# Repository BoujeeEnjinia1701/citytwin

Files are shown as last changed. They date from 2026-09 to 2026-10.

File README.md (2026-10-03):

# CityTwin

     

**Area:** Smart Cities · **TRL:** 3 of 9 (proof of concept on paper) · **Value-engineering target:** $750 USD for the kiosk (hypothetical control target; estimated cost $778.00) · **Difficulty:** 3 of 5

A city dashboard built on TwinKit that brings the smart city nodes together on a map and in a public kiosk, with open data export and privacy rules built in.

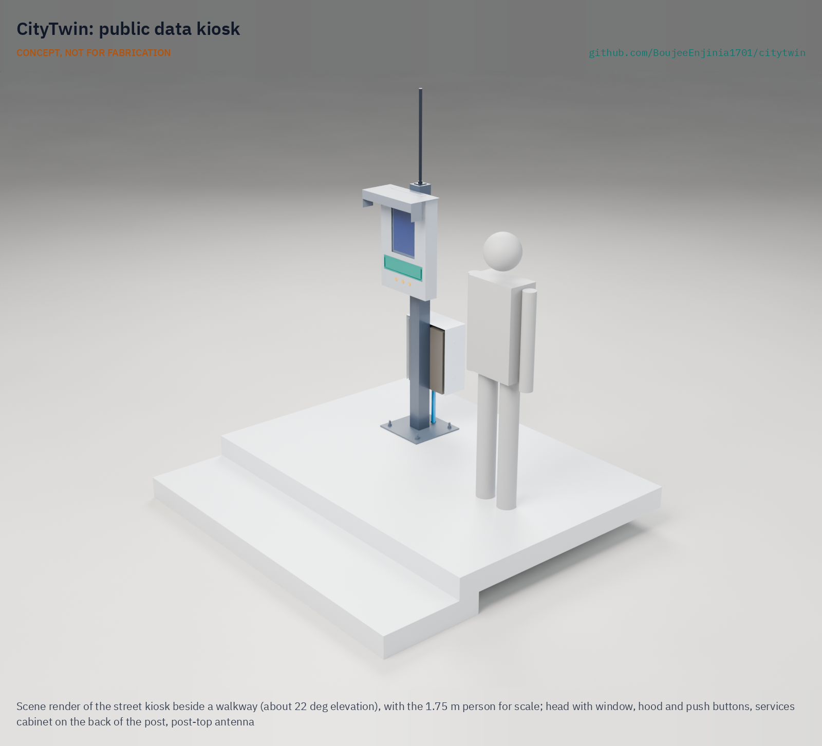
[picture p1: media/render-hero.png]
CityTwin: public kiosk for the city dashboard, photoreal render


[Interactive 3D model](media/viewer.html) · [Concept blueprint (PDF)](media/concept-blueprint.pdf) · [General arrangement CTW-DWG-001 (PDF)](cad/drawings/CTW-DWG-001.pdf) · [Calculations CTW-CAL-001](docs/04-calcs/01-sizing.md) · [Prototype build plan](docs/05-build-plan.md) · [Review note](docs/REVIEW.md)

## Concept rationale

One open, public view of street data builds trust and lets residents and planners use the same evidence. CityTwin takes the counts and levels that the lab's smart city nodes already send, checks each record against a strict schema, applies the same privacy rules to everything it publishes, and shows the result on one map, in hourly open data files and on a kiosk in the street. The kiosk tells a passer-by what is measured nearby, who is responsible and how long data is kept, next to the current values.

It is open and garage-buildable because trust depends on being able to check the system. The software runs on one small TwinKit gateway that a city, a university or a neighborhood group can own outright, and the kiosk is a steel post, a folded aluminum head, a color e-paper screen and an electrical cabinet: parts a local fabricator and electrician can supply and inspect.

## Burning platform

Cities are growing and are adding sensors to manage that growth, but residents often do not trust how the data is used. About 55 % of the world's people live in urban areas, projected to reach 68 % by 2050 ([UN DESA, 2018](https://www.un.org/development/desa/en/news/population/2018-revision-of-world-urbanization-prospects.html)). In a 2019 survey, 66 % of U.S. adults said the risks of government data collection about them outweigh the benefits, and 84 % said they have very little or no control over it ([Pew Research Center](https://www.pewresearch.org/internet/2019/11/15/americans-and-privacy-concerned-confused-and-feeling-lack-of-control-over-their-personal-information/)).

Where the rules are unclear, projects stall. In Toronto, the former Ontario privacy commissioner resigned from the Sidewalk Labs project because de-identification at the point of collection could not be guaranteed ([CBC News](https://www.cbc.ca/news/canada/toronto/ann-cavoukian-sidewalk-data-privacy-1.4872223)), and the project was withdrawn in May 2020 ([Sidewalk Labs](https://medium.com/sidewalk-talk/why-were-no-longer-pursuing-the-quayside-project-and-what-s-next-for-sidewalk-labs-9a61de3fee3a)). Street data that is aggregated at the source, published openly and shown where it is collected is a practical answer.

## Where it could be used

### By industry

| Industry | Use |
| --- | --- |
| Municipal government | One map of counts, curb use, air, noise, heat and flooding for planning, with a public kiosk and open data portal feed |
| Transport and road safety | Before and after evidence for street changes, combining CurbCount, CrossSafe, LoadZone and PotholeLog data |
| Environmental health | Neighborhood air, noise and heat maps for health departments and community groups |
| Water and drainage | FloodGauge levels next to rainfall and street data for drainage crews |
| Universities and schools | Open, documented street data and a kiosk for teaching and research |
| Business districts and transit hubs | Kiosks at plazas and stations that show local conditions and explain the sensors |

### By country or region

| Country or region | Why it matters there |
| --- | --- |
| European Union | High-value datasets, including earth observation and environment and mobility, must be published in machine-readable formats through APIs and bulk download under [Implementing Regulation (EU) 2023/138](https://eur-lex.europa.eu/eli/reg_impl/2023/138/oj/eng), applying from June 2024 |
| Canada | The Toronto Quayside project showed how data governance can decide a smart city project ([CBC News](https://www.cbc.ca/news/canada/toronto/ann-cavoukian-sidewalk-data-privacy-1.4872223)) |
| Taiwan | [Civil IoT Taiwan](https://ci.taiwan.gov.tw/) publishes air quality, water and disaster sensor data openly; CityTwin offers a small, open counterpart for a single city or district |
| Sub-Saharan Africa | [AirQo](https://airqo.net/) runs more than 400 low-cost air sensors in 14 African countries, showing demand for open community sensing where city budgets are small |
| India and Nigeria | With China, they account for 35 % of projected urban growth to 2050 ([UN DESA](https://www.un.org/development/desa/en/news/population/2018-revision-of-world-urbanization-prospects.html)); fast-growing cities need low-cost, open street data |
| Brazil | The general data protection law applies to public bodies as well as companies ([Lei 13.709/2018](https://www.planalto.gov.br/ccivil_03/_ato2015-2018/2018/lei/l13709.htm)), which favors systems that publish only aggregates |

## What sparked the idea

The starting point was Amsterdam's sensor register. A city regulation in force from December 1, 2021 requires anyone who places a sensor on or beside a street, on a vehicle or vessel, or in a publicly accessible building to report it in advance and state what data it collects, with exemptions for private individuals and for police and public order use; sensors already in place had six months to comply, and the city keeps a register of the reports so that people in public space can see what data is being gathered ([Gemeenteblad 2021, 368183](https://zoek.officielebekendmakingen.nl/gmb-2021-368183.html); [Sensorenregister Amsterdam](https://sensorenregister.amsterdam.nl/)). The register answers "who owns this and what does it collect?" on a website. CityTwin carries the same answer to the pavement: a notice plate with a QR code to the sensor register, the live counts and levels beside it, and open data files behind it, on hardware a city or neighborhood group can own.

## Problem

City data sits in separate vendor dashboards, and residents rarely see the data collected on their streets.

## Concept

A city dashboard built on TwinKit that brings the smart city nodes together on a map and in a public kiosk, with open data export and privacy rules built in.

CityTwin software on a TwinKit gateway receives counts and levels from the nine smart city node types, rejects anything outside each node's schema, stores the rest, suppresses small counts and movement traces, and publishes hourly CSV and GeoJSON files one way to a public host. The kiosk is a steel post with a 13.3 in color e-paper screen at about 1.46 m, three buttons at about 1.12 m, a data notice plate with a QR code, a lit sun hood, and a locked cabinet holding the mains protection, a 12 V supply and the gateway.

TRL 3 calculations ([CTW-CAL-001](docs/04-calcs/01-sizing.md)): a 46-node reference neighborhood sends 5,616 uplinks a day and loses 0.61 %, well within one gateway; data on the kiosk is at most 25.9 min old; kiosk and gateway draw 9.2 W from the mains with the hood light dimmed; the kiosk weighs about 64 kg with its outdoor sun shield and its post is stressed to 26.6 MPa in a 35 m/s gust with a 1.5 factor. A button's LED ring answers a press at once and the new layer follows in 19.8 s, within the 25 s target; and a sheltered pilot site at 0 to 35 °C air leaves about 5 K of margin for the screen and the backup pack. Cost: the value-engineering target for the pilot kiosk is $750 (a hypothetical control target, not a limit) and the estimated cost of the constructable design is $778.00, $28.00 over the target once the parts needed to build it are counted (R16; savings are listed in the [design decisions register](docs/06-design-decisions.md)). Not met: backup time with an aged, cold pack (1.63 h against 2 h, until TwinKit fits a pack of at least 1.84 Ah) and the street climate range, so the pilot kiosk stands on a sheltered site and any outdoor site gets a cabinet sun shield and a shaded screen. Ingest of every node type is at risk until PotholeLog, DockHub and CrossSafe agree their interfaces. See the [requirements](docs/03-requirements.md) and the decision records [CTW-DDR-001](docs/decisions/0001-trl2-review-decisions.md), [CTW-DDR-002](docs/decisions/0002-recommendations-accepted.md) and [CTW-DDR-003](docs/decisions/0003-design-for-construction.md).

Full design precis: [docs/02-concept.md](docs/02-concept.md)

## Key components

1. Base plate and anchors
2. 100 mm square steel post, 1.75 m
3. Folded aluminum display head
4. Polycarbonate front window
5. 13.3 in color e-paper display (E Ink Spectra 6, 1600 x 1200 px)
6. Kiosk controller (Raspberry Pi Zero 2 W class, wired to the gateway)
7. Three stainless push buttons with LED rings
8. Data notice plate with QR code to the sensor register
9. Sun and rain hood with night light (dimmed to about 0.3 W)
10. Lockable services cabinet
11. Mains protection (30 mA RCBO and surge protector)
12. 12 V DIN power supply
13. TwinKit gateway with LiFePO4 backup, on its own DIN rail (costed in TwinKit)
14. LoRaWAN antenna on the post top (TwinKit BOM)
15. Conduit and cabling
16. Map dashboard, open data export and data governance templates (software and documents)
17. Cabinet sun shield for outdoor sites (BOM item 19)
18. Display carrier holding the e-paper panel and the head electronics (BOM item 20)
19. Fixings, glazing tape and gaskets (BOM item 21)

The priced bill of materials is in [bom/bom.csv](bom/bom.csv): $778.00 for the pilot kiosk, $808.00 with the outdoor sun shield, $1,068.00 for the pilot kiosk with the TwinKit gateway.

## Building the prototype

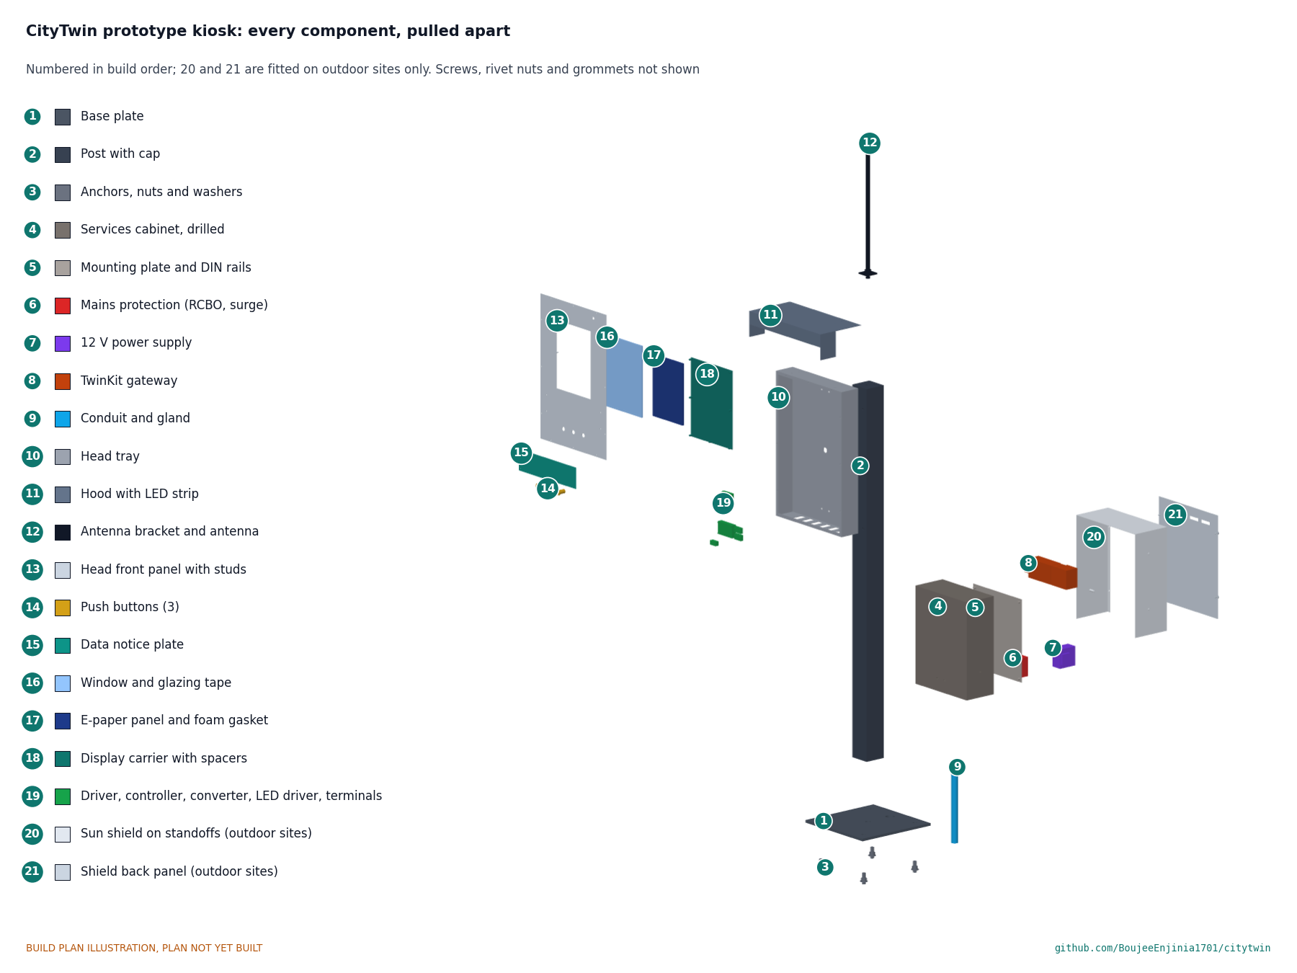
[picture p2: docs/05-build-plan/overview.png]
CityTwin prototype kiosk: every component pulled apart and numbered in build order


The [prototype build plan](docs/05-build-plan.md) (CTW-BLD-001) shows, in pictures, how to make each of the 21 components of the kiosk and put them together in sixteen steps; nothing has been built yet. The made parts are a welded and galvanized steel post and base plate, a folded aluminum head tray with a removable front panel, a display carrier, a hood, a notice plate, an antenna bracket and, for outdoor sites, a sun shield; the bought cabinet is drilled, and the mains wiring is left to a qualified electrician. Writing the plan made the design buildable: the head, cabinet and hood are now fixed to rivet nuts in the post, the head opens at the front, the screen is held by a carrier on studs, and cable routes, a vent hole for galvanizing and fixings were added (CTW-DDR-003, accepted by Amish on 2026-10-02). Every picture is drawn from the model, and the model checks that each part touches what it should and clears what it should not.

## Safety

> Privacy by design: no images, audio recordings or personal identifiers leave the device; only aggregate counts or levels are stored. Check local data protection law before any deployment. Mains wiring must be done or checked by a qualified electrician and follow local electrical code.
>
> The kiosk is a roughly 64 kg steel post: install it only with the asset owner's permission, on a footing designed for local wind loads, with no sharp edges at head height. The TwinKit gateway contains a LiFePO4 backup pack: use a pack with a built-in BMS and fuse, and keep the cabinet out of direct sun or under its sun shield, because in sun it can run far above the pack's 45 °C charge limit. CityTwin is not a public warning system.

## Repository layout

| Folder | Contents |
| --- | --- |
| `docs/` | Problem, concept, requirements, calculations and design decisions |
| `cad/src/` | build123d Python source, the source of truth for all geometry |
| `cad/step/`, `cad/stl/` | Exported models for FreeCAD, other CAD tools and printing |
| `cad/drawings/` | 2D sketches and dimensioned drawings |
| `bom/` | Bill of materials |
| `electronics/` | KiCad schematics and PCB layouts |
| `firmware/` | Microcontroller code |
| `media/` | Renders, perspectives and photos |
| `build-log/` | Dated prototyping notes |

## Documentation

Controlled documents follow the portfolio [documentation standard](.kit/STANDARDS.md). Each carries a document ID (CTW-PRC-001 for the precis), a version and a revision history. Branded PDFs are built with `python .kit/render.py` and attached to GitHub Releases when a document is tagged, for example `CTW-PRC-001/v1.0`.

## Credits

Designed by Amish Chadha. See [CONTRIBUTORS.md](CONTRIBUTORS.md) for roles. To cite this design, use [CITATION.cff](CITATION.cff) (GitHub shows it as "Cite this repository").

AI assistance (Claude) was used to accelerate concept renders, prototype documentation and first-pass sizing calculations. Design direction and all decisions are Amish Chadha's, recorded in this repository's decision records (`docs/decisions/`).

## Licenses

- **Hardware** (CAD, drawings, BOM, electronics): [CERN-OHL-S v2](LICENSE)
- **Software** (firmware, scripts, notebooks): [MIT](LICENSE-SOFTWARE)

A project of the [Design Molecule](https://designmolecule.com) lab.

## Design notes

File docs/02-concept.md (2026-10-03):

---
doc_id: CTW-PRC-001
title: CityTwin design precis
project: CityTwin
doc_type: Design precis
version: "0.8"
status: Draft
date: '2026-10-02'
author: Amish Chadha
license: CERN-OHL-S-2.0
revisions:
- version: "0.1"
  date: '2026-09-25'
  author: Amish Chadha
  change: "Initial scaffold"
- version: "0.2"
  date: '2026-09-25'
  author: Amish Chadha
  change: "Populate to TRL 2 (architecture, privacy rules, kiosk massing model, first-order numbers, safety, open questions)"
- version: "0.3"
  date: '2026-09-25'
  author: Amish Chadha
  change: "TRL 3 update with adopted choices per CTW-DDR-001, numbers from CTW-CAL-001, parametric model and GA drawing CTW-DWG-001, TwinKit layout in the cabinet, pull paths for PotholeLog and DockHub"
- version: "0.4"
  date: '2026-09-25'
  author: Amish Chadha
  change: "Recommendations accepted by Amish (DDR-002)"
- version: "0.5"
  date: '2026-10-01'
  author: Amish Chadha
  change: "Constructable design (CTW-DDR-003): mass, wind and cost figures updated; build plan CTW-BLD-001 and register CTW-DEC-001 linked"
- version: "0.6"
  date: '2026-10-01'
  author: Amish Chadha
  change: Budget treated as a value-engineering target
- version: "0.7"
  date: '2026-10-02'
  author: Amish Chadha
  change: 'Decisions of 2026-10-02 (CTW-DEC-001 v0.3): permanent shade for outdoor sites, pull file format, CrossSafe uplink request, R20 kept post-pilot, antenna walk test, languages, sheltered pilot near Irving as first candidate'
- version: "0.8"
  date: '2026-10-02'
  author: Amish Chadha
  change: "Pull-path CSV column list and version field published for agreement with PotholeLog and DockHub (CTW-DEC-001, D11)"
---

# CityTwin design precis

## Summary

CityTwin is open software that runs on a TwinKit gateway and brings the lab's smart city nodes onto one map, plus a public street kiosk that shows the same data to residents. Nodes send counts and levels over LoRaWAN; CityTwin checks every record against a schema, stores it, publishes hourly open data files and draws the map. The kiosk is a steel post with a 13.3 in color e-paper screen at eye height, three push buttons, a notice plate that says what is measured and by whom, and a locked cabinet that holds the mains protection and the gateway.

The TRL 3 calculations (CTW-CAL-001) show that the data side has wide margin: the 46-node reference neighborhood sends 5,616 uplinks a day and loses 0.61 % to collisions and downlink blanking, and the store and open export are small. The kiosk takes 9.2 W from the mains with the gateway, weighs about 64 kg with its outdoor sun shield and stands up to a 35 m/s gust with a large margin. With Amish's decisions of 2026-09-25 (CTW-DDR-002), the button LED ring acknowledges a press at once and the new layer follows in 19.8 s (R10, restated to 25 s, met on paper), and the pilot range of 0 to 35 °C air leaves about 5 K of margin for the panel and the backup pack (R12, met on paper). Against the $750 value-engineering target (a hypothetical control target), the parts added on 2026-10-01 to make the kiosk buildable (CTW-DDR-003) take the estimated cost of the pilot kiosk to $778.00, $28.00 over the target (R16; see the Value engineering section of [CTW-DEC-001](06-design-decisions.md)). Two requirements are not met: the TwinKit backup lasts only 1.63 h with an aged, cold pack (R18), until TwinKit fits a larger pack; and a street kiosk in sun or frost is outside the panel's 0 to 40 °C rating (R20), which is why the pilot is sited in shelter. The general arrangement is drawing [CTW-DWG-001](../cad/drawings/CTW-DWG-001.pdf), and the illustrated build plan is [CTW-BLD-001](05-build-plan.md).

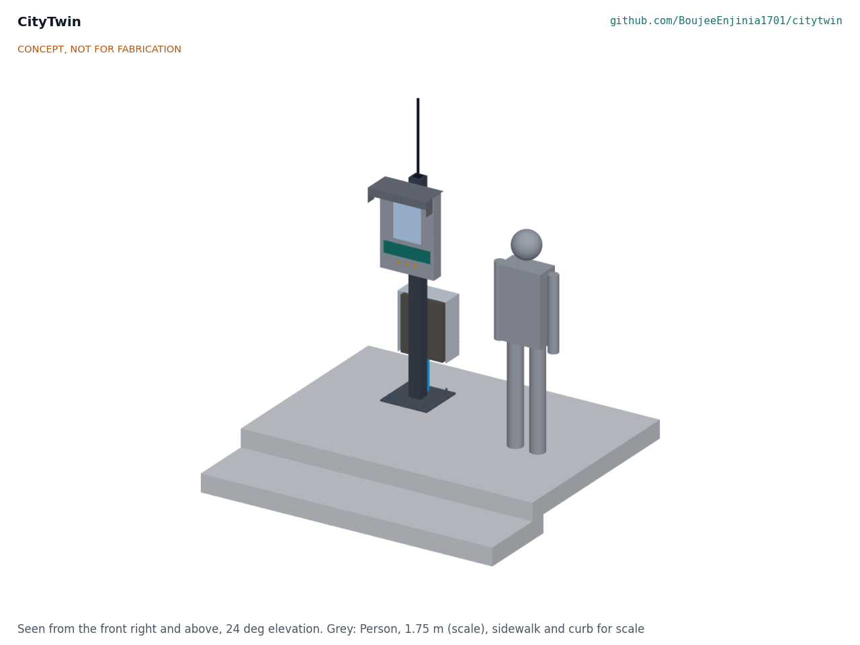
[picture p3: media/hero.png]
Hero render


*Figure 1. CityTwin kiosk on a sidewalk, with a 1.75 m person for scale. Rendered from the parametric model `cad/src/model.py`.*

## How it works

1. **Collect.** The seven LoRaWAN node types (CurbCount, CrossSafe, LoadZone, HeatMap Node, FloodGauge, AirStreet, NoiseMap) send small uplinks to the TwinKit gateway's concentrator. PotholeLog uploads daily road summaries over depot Wi-Fi to the fleet operator's server, and DockHub syncs over LTE-M to its own back end. Under CTW-DDR-001 D11 the gateway pulls their published aggregates (road segment files once a day, dock-hour rows every hour) by outbound HTTPS, so it still accepts no inbound connection; the path is to be agreed with those projects. CrossSafe has no LoRaWAN uplink yet (its radio links the two sides of a crossing point to point), so its layer waits for that interface.
2. **Check.** A decoder for each node type turns the payload into named fields. Any field outside that type's schema is rejected and logged, so a changed or faulty node cannot push anything but counts and levels into the store.
3. **Store.** Records go into the TwinKit time-series database with node ID, location and time. Raw records are kept for two years and hourly aggregates indefinitely (D6); ten years of aggregates and two years of raw data take about 21 GB of the gateway's card.
4. **Apply the privacy rules.** Before anything is published, people and vehicle counts below 5 per hour (D6) become "fewer than 5", PotholeLog data is published only per road segment and per day, and DockHub data only per dock per hour. No card IDs, vehicle tracks or node-level raw streams leave the gateway.
5. **Publish.** Every hour the gateway writes CSV and GeoJSON files with a documented schema and pushes them one way to a public host under CC BY 4.0 (D7), about 0.86 MB of CSV a day. An OGC SensorThings API endpoint on the public host remains a suggestion for later work.

   The daily pull files of D11 (decided 2026-10-02) use one fixed, versioned column list, proposed here for agreement with PotholeLog and DockHub. One file per operator, layer and UTC day, at a fixed HTTPS address, named `<operator>_<layer>_<YYYY-MM-DD>_v1.csv`, comma separated, UTF-8, one header line. Version 1 columns: `schema_version` (the integer 1; it changes when a column is added, renamed or removed), `operator_id`, `node_id` (a pseudonymous code, never a serial number or name), `node_type`, `segment_id` (street segment code for PotholeLog files, empty otherwise), `site_cell` (grid cell code, not an address), `period_start_utc` (ISO 8601), `period_hours` (1 for hourly aggregates), `measure` (`count`, `level` or `score`), `value`, `unit`, `quality` (`ok`, `estimated` or `suppressed`) and `suppressed_below` (5 when the value is suppressed, otherwise empty). Counts and levels only, as in R3.
6. **Show.** The web map has one layer per node type, a time slider, node health and an "as of" timestamp. The kiosk controller pulls a pre-rendered 1600 x 1200 image of the selected layer from the gateway every 10 min, or when a button is pressed, and writes it to the e-paper. Each image carries its timestamp, so a stale screen during an outage says so. Two controller rules follow CTW-DDR-002: a pressed button's LED ring lights within 0.5 s and stays lit until the new image is drawn, and the hood light runs dimmed to about 0.3 W from dusk.

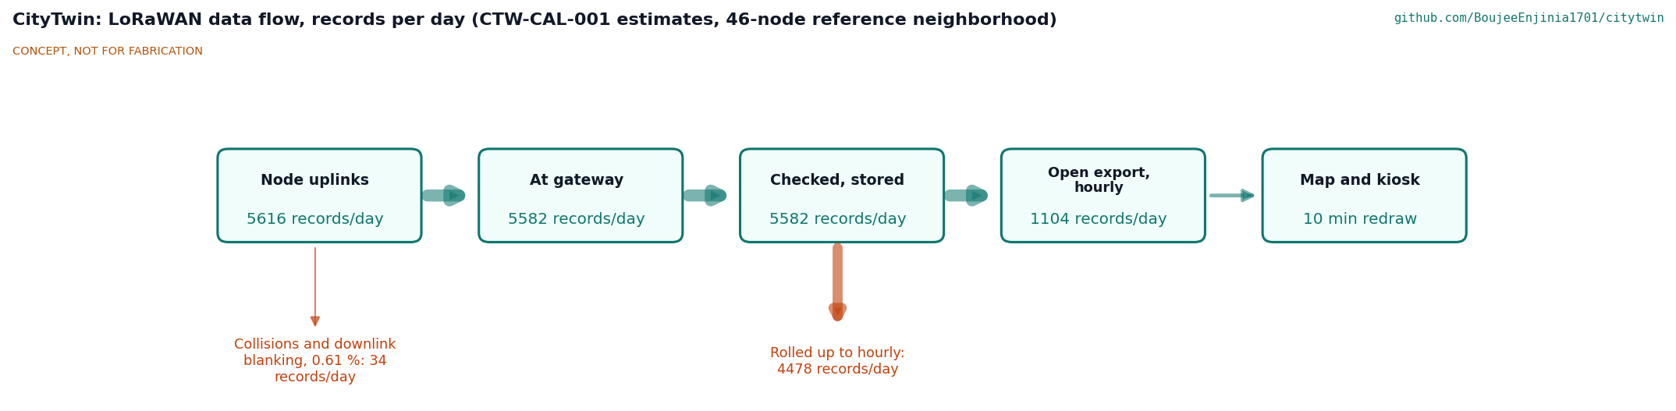
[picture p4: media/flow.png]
Data flow


*Figure 2. LoRaWAN data flow for the reference neighborhood, in records per day (CTW-CAL-001): 0.61 % lost to collisions and downlink blanking, and 5,582 stored records rolled up to 1,104 hourly records for the open export. PotholeLog and DockHub rows, pulled from their operators, are not shown.*

## Main components

Table 1. Main components. Numbers match `bom/bom.csv` and Figure 3.

| # | Component | Choice | Notes |
| --- | --- | --- | --- |
| 1 | Base plate and anchors | 400 x 400 x 12 mm galvanized plate, four M16 anchors on a 300 mm square | Into a footing or existing slab; 1.94 kN per anchor at the design gust |
| 2 | Post | 100 x 100 x 4 mm square hollow section, 1.75 m | Carries head, hood, cabinet and antenna |
| 3 | Display head enclosure | Folded 2 mm aluminum, about 460 x 100 x 680 mm | IP54 target, vents underneath |
| 4 | Front window | 6 mm UV-stabilized polycarbonate, anti-glare | Replaceable if scratched |
| 5 | E-paper display | 13.3 in E Ink Spectra 6, 1600 x 1200 px, about 150 px per inch | [Waveshare 13.3inch e-Paper HAT+ (E)](https://www.waveshare.com/13.3inch-e-paper-hat-plus-e.htm): about 19 s full refresh, no partial refresh, 0 to 40 °C ([manual](https://www.waveshare.com/wiki/13.3inch_e-Paper_HAT+_(E)_Manual)) |
| 6 | Kiosk controller | Raspberry Pi Zero 2 W class, wired Ethernet to the gateway | Only pulls and draws images |
| 7 | Push buttons | Three 19 mm stainless buttons with LED rings, at about 1.12 m | Layer, time range, "about this sensor" |
| 8 | Data notice plate | 400 x 100 mm, icons in the style of the open [DTPR](https://dtpr.io/) standard, QR code and short URL | Says what is measured, who is responsible and for how long data is kept |
| 9 | Sun and rain hood with light | Folded aluminum, 2 W LED strip with dusk sensor, dimmed to about 0.3 W | Shades the screen by day, lights it at night (about 219 lx) |
| 10 | Services cabinet | Lockable steel, 360 x 160 x 460 mm, IP55, two 320 mm DIN rails, door on the back | Only place with mains voltage |
| 11 | Mains protection | 6 A 30 mA RCBO and Type 2 surge protector | Installed or checked by an electrician |
| 12 | 12 V DIN power supply | 60 W, certified, SELV output | Feeds gateway and head |
| 13 | TwinKit gateway | TwinKit DIN gateway on the upper rail as in TWK-DWG-001 (294 mm of rail), LiFePO4 pack inside its UPS module | Costed in TwinKit ($290.00); runs CityTwin software |
| 14 | LoRaWAN antenna | TwinKit antenna on a post-top bracket, tip at 2.38 m, coax to the gateway's SMA bulkhead | Low for a gateway; see open questions |
| 15 | Conduit and cabling | Mains conduit into the cabinet; 12 V and Ethernet up the post | |
| 16 to 18 | Software and templates | Map dashboard, open data export, governance templates | MIT and CC licensed; no parts cost |
| 19 | Cabinet sun shield (outdoor sites) | Folded 1.5 mm aluminum over the top, both sides and the door (lift-off back panel), 25 mm air gap, open bottom, vent slots at the top | CTW-DDR-002; cuts the cabinet's rise in sun from 18.7 K to 7.2 K; not needed on the sheltered pilot site |

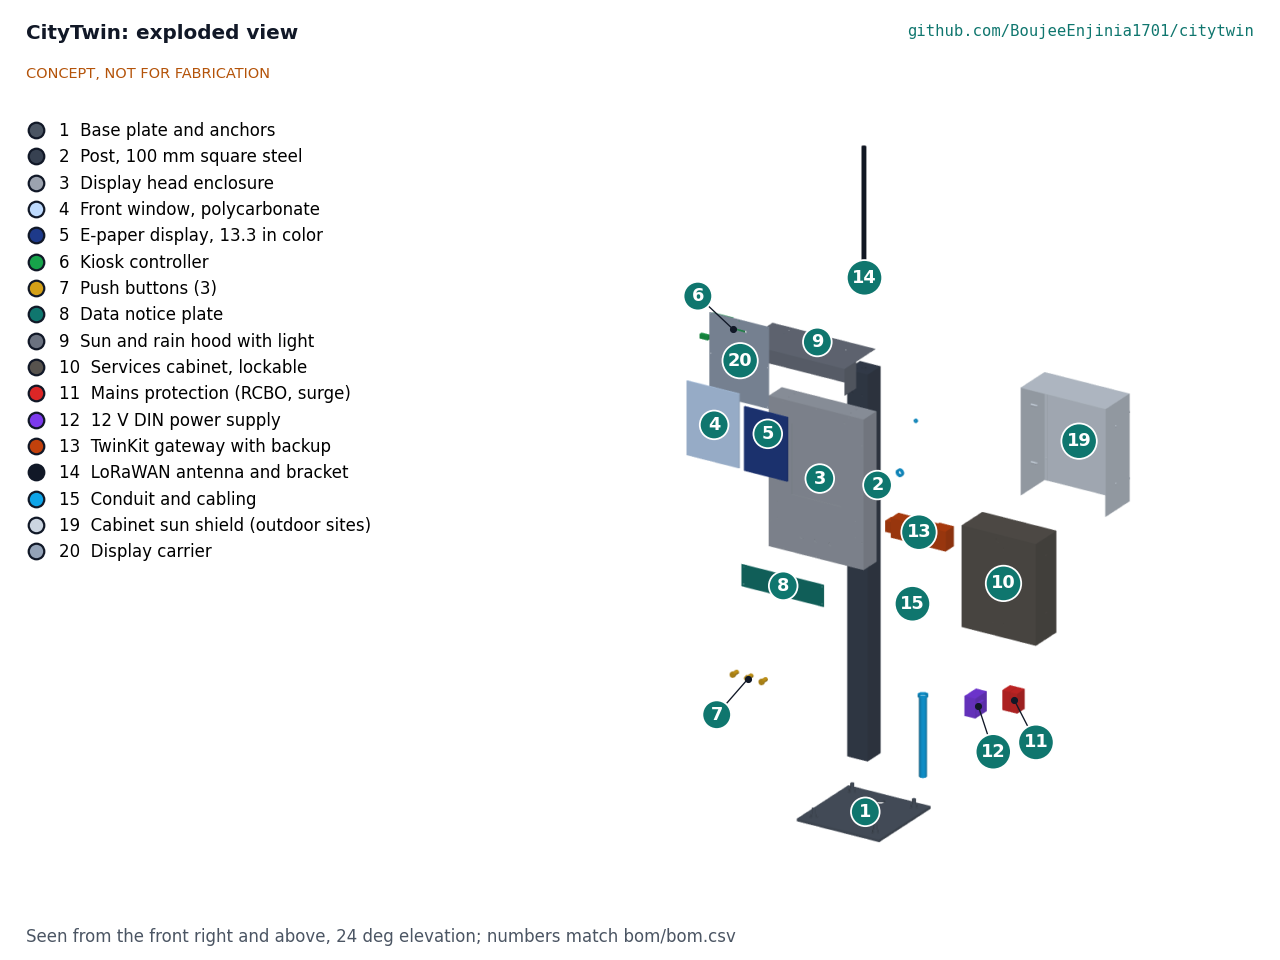
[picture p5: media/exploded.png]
Exploded view


*Figure 3. Exploded view with BOM numbers.*

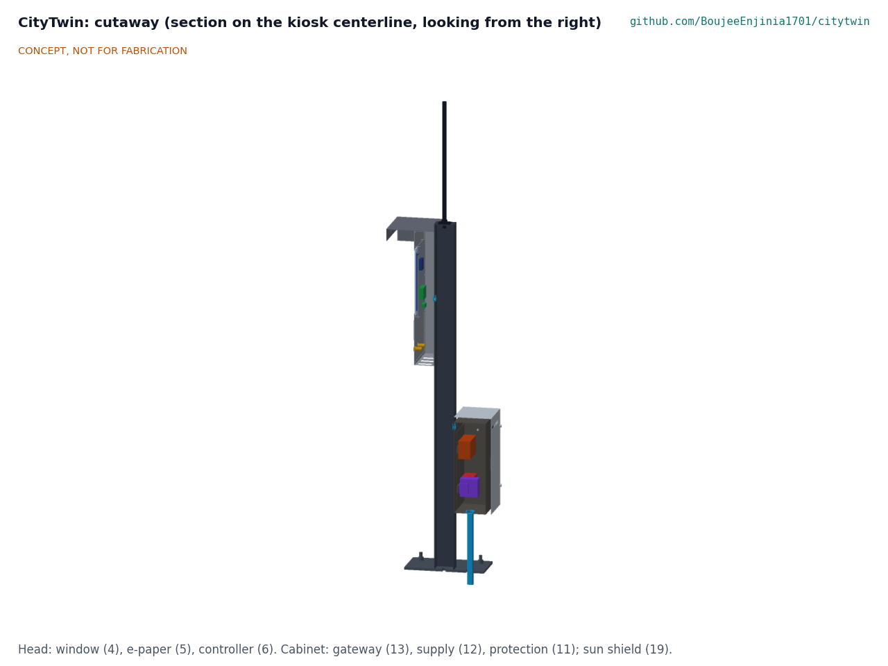
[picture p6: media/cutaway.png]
Cutaway


*Figure 4. Section on the kiosk centerline, looking from the right: window (4), e-paper (5) and controller (6) in the head; TwinKit gateway (13) on the upper rail, power supply (12) and mains protection (11) on the lower rail of the cabinet, under the sun shield (19).*

## Key numbers

All values are from the TRL 3 calculation note CTW-CAL-001 v0.2, which states every assumption; the tags refer to lines of its script.

Table 2. Data load for the reference neighborhood (CTW-DDR-001 D9).

| Node type | Nodes | Uplinks per node per day | Uplinks per day | Basis |
| --- | --- | --- | --- | --- |
| CurbCount | 8 | 96 | 768 | 14 B per 15 min bin (CBC-CAL-001) |
| CrossSafe | 4 | 24 | 96 | Hourly summary (CityTwin assumption; no LoRaWAN uplink defined in CrossSafe) |
| LoadZone | 12 | 124 | 1,488 | 100 state changes and 24 heartbeats, 12 B (LDZ-CAL-001) |
| HeatMap Node | 6 | 96 | 576 | 20 B per 15 min (HMN-CAL-001) |
| FloodGauge | 4 | 96 | 384 | 15 min normal mode; 1 min in events (FLG-CAL-001) |
| AirStreet | 6 | 288 | 1,728 | 20 B per 5 min (AST-CAL-001) |
| NoiseMap | 6 | 96 | 576 | 22 B per 15 min (NSM-CAL-001) |
| **Total** | **46** | | **5,616** | R2 met on paper |

Table 3. System and kiosk numbers (CTW-CAL-001).

| Quantity | Value | Requirement |
| --- | --- | --- |
| Radio airtime at SF9 | 1,309 s a day, 0.189 % of each of 8 channels | |
| Radio loss | 0.38 % collisions plus 0.23 % while the gateway sends LoadZone sign downlinks; 0.94 % plus 0.23 % in a storm peak hour | R2 met on paper |
| Gateway capacity | 14,075 records a day of 20 B at SF9 before loss reaches 1 % | R2 |
| Storage | 2.89 GB a year raw; 20.9 GB for two years raw and ten years of hourly aggregates | Fits 56 GB with TwinKit's own data |
| Open export | 7,128 rows a day, 0.86 MB CSV and 2.85 MB GeoJSON | R6 |
| Worst data age | 25.9 min on the kiosk, 15.6 min on the web map | R8 met on paper, thin margin |
| Button to new layer | LED ring in about 30 ms; layer in 19.8 s (0.79 s transfer plus 19 s refresh) | R10 (restated: 0.5 s and 25 s) met on paper |
| Text and night light | 7 mm capitals are 41 px and 16.0 arcmin at 1.5 m; about 219 lx from the hood light dimmed to 0.3 W | R9 met on paper |
| Hood shading | 13 %, 31 % and 63 % of the window shaded with the sun at 30°, 45° and 60° in front | |
| Head and panel, pilot | Panel 35.1 °C at 35 °C air in shade | R12 met on paper |
| Head and panel, street | About 79 °C in low sun and 45.1 °C in shade at 45 °C air; 13.5 W to keep an insulated panel bay at 0 °C in -20 °C air | R20 **not met** |
| Cabinet | 7.96 W inside; air 4.4 K above ambient in shade, 18.7 K in sun, 7.2 K in sun behind the sun shield; pack 5.6 K under its 45 °C charge limit at 35 °C air; with the shield the pack stays under the limit in full sun up to 37.8 °C air | R12 met on paper |
| Power | 9.2 W from the mains, 81 kWh a year; 12 V peak 26.7 W on a 60 W supply | R15 met on paper |
| Wind at 35 m/s | 821 N, 839 N·m at the base; 26.6 MPa in the post with a 1.5 factor; 1.94 kN per anchor | R13 met on paper |
| Mass | 63.5 kg with the sun shield | Two-person lift |
| Backup | 2.40 h new, 1.63 h aged at 0 °C (TwinKit); a pack of at least 1.84 Ah would give 2 h | R18 **not met** in the worst case |
| Pilot kiosk parts cost | $778.00; $808.00 with the outdoor sun shield | R16 over the value-engineering target by $28.00 ($750 target, CTW-DEC-001) |
| Kiosk and gateway | $1,068.00 | R17 reported |

## Key design choices

Items D1 to D11 in CTW-DDR-001 and N1 to N6 in CTW-DDR-002 are decided by Amish, 2026-09-25: go with recommendation.

- **Color e-paper rather than an LCD (D2).** E-paper is readable in direct sun, draws almost nothing between refreshes and keeps its image in an outage. A 1,000-nit outdoor LCD would respond instantly and allow touch, but costs more, draws tens of watts and needs cooling. A monochrome panel would refresh faster but lose the color layers. Decided: color e-paper for the street kiosk, with an indoor LCD variant for libraries and city hall lobbies (not modeled at TRL 3). R10 is restated for the street kiosk (LED ring within 0.5 s, layer within 25 s) and keeps 5 s for the LCD variant.
- **Sheltered pilot (D3, N5).** The panel is rated 0 to 40 °C. The pilot kiosk stands where the screen gets no direct sun, in air of 0 to 35 °C, which leaves about 5 K of margin; the heater and shading study for a street kiosk is CTW-CAL-001 section F.
- **Site rules for any outdoor kiosk (N4).** Fit the cabinet sun shield (item 19); site it only in permanent shade (decided by Amish, 2026-10-02), with the screen oriented so it gets no direct sun (for example north-facing in the northern hemisphere); fit the insulated, heated panel bay (13.5 W at -20 °C) only if the partner city has frost. The shield keeps the backup pack under its 45 °C charge limit in full sun up to about 37.8 °C air.
- **Buttons, not a touch screen (D8).** Three stainless buttons survive vandalism and weather and suit e-paper's slow refresh; the QR code hands richer use to the visitor's phone.
- **Gateway inside the kiosk cabinet (D4).** One site, one mains feed and one locked box for a pilot. The TwinKit gateway sits on its own DIN rail exactly as TwinKit lays it out, with a coax lead to the post-top antenna in place of its whip. The cost is a low antenna (tip at 2.38 m), which shortens LoRaWAN range; a rooftop gateway is the choice for a full neighborhood.
- **Mains power (D5).** Kiosk and gateway need 0.222 kWh a day. A solar head-only variant is kept for sites without power (not modeled at TRL 3).
- **One-way publishing and outbound pulls (D10, D11).** The gateway pushes open data files out and fetches sibling aggregates out, and accepts no inbound connections from the internet, in line with TwinKit's advice to keep the gateway off public networks until it is hardened.
- **Privacy rules in the gateway, not only in the nodes (D10).** Nodes already send counts and levels only; enforcing a schema and small-count suppression (5 per hour, D6) again at the gateway protects against a changed node or a future node type that is less careful.
- **Open data license (D7).** CC BY 4.0.
- **Value-engineering target (D1, N1).** The value-engineering target ($750, a hypothetical control target, not a limit) covers the pilot kiosk; the gateway is costed in TwinKit and the outdoor sun shield is reported separately.
- **Backup pack (N3).** TwinKit is asked for a pack of at least 1.84 Ah in cabinet installs, so the gateway rides through 2 h when the pack is aged and cold.

## Safety

> **Safety:** The services cabinet contains mains voltage (230 V or 120 V). The mains feed, RCBO, surge protector and earthing must be installed or checked by a qualified electrician and follow local electrical code. Keep the cabinet locked, fit an earth bond to the post, head and hood, and carry only 12 V SELV up to the head.

> **Safety:** The TwinKit gateway contains a LiFePO4 backup pack. Use a pack with a built-in BMS and fuse, charge it only through the TwinKit UPS module, and keep it within its temperature limits. CTW-CAL-001 finds the sealed cabinet 18.7 K above the air in full sun: at 45 °C air the pack would be near 64 °C, and in frost it cannot charge. The sun shield cuts the rise to 7.2 K but does not remove the limit above about 38 °C air. The UPS charger's 0 to 45 °C lockout must never be defeated; the pilot site must keep the cabinet out of direct sun, and any outdoor site must fit the sun shield.

> **Safety:** The kiosk is a roughly 64 kg steel post beside a walkway. Install it only with the asset owner's permission and a permit, on a footing designed for local wind and impact loads, with no sharp edges or protruding corners at head height, and keep a clear walkway width around it as local rules require. Lift it with two people or a hoist.

> **Safety:** Privacy by design: no images, audio recordings or personal identifiers are taken in, stored or published; only aggregate counts or levels. Check local data protection law, and carry out a privacy impact assessment before any deployment. CityTwin is not a public warning system: do not rely on it for flood or emergency alerts.

## Open questions

- [ ] Pull paths for PotholeLog segment files and DockHub hourly aggregates (D11): daily CSV files on a fixed HTTPS address at each operator, with a published column list and a version field (decided 2026-10-02); hosts and the PotholeLog side still to agree with those projects.
- [ ] A LoRaWAN uplink from CrossSafe, whose radio now runs point to point between the two sides (R1). Decided 2026-10-02: CrossSafe is asked for an hourly LoRaWAN summary uplink from one side of the crossing, and CityTwin shows no CrossSafe layer until it exists.
- [ ] Backup time (R18): TwinKit to confirm a pack of at least 1.84 Ah for cabinet installs (decided, CTW-DDR-002 N3; cross-repo action).
- [ ] Street climate (R20): the panel still exceeds its rating at 45 °C air even in shade; a wider-range panel, if one exists, remains the only full fix. Decided 2026-10-02: R20 stays a post-pilot target, outdoor sites only in permanent shade with the sun shield, a panel rated above 40 °C sought at TRL 4, the heated bay only for a frost city.
- [ ] Antenna height needed for the reference neighborhood with the gateway in the cabinet. Decided 2026-10-02: keep the post-top antenna at 2.38 m for the pilot and walk-test coverage at TRL 4; a rooftop gateway, not a taller mast, if nodes fall short.
- [x] Which languages and scripts the kiosk shows, and how residents ask questions or report a fault. Decided 2026-10-02: English plus the partner city's most widely spoken other language in its own script, with a QR code and a phone or text number on the notice plate; refined in co-design.
- [ ] First partner city or neighborhood, and co-design sessions with residents on what the kiosk should show (CTW-DDR-001 O1). Decided 2026-10-02: first candidate a city within easy reach of Irving, Texas, with an active open-data program, the pilot in a sheltered public lobby such as a library or transit center; co-design sessions still to hold.

Concept media: [blueprint sheet](../media/concept-blueprint.pdf), [interactive 3D model](../media/viewer.html). General arrangement: [CTW-DWG-001](../cad/drawings/CTW-DWG-001.pdf). Calculations: [CTW-CAL-001](04-calcs/01-sizing.md).

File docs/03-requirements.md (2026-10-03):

---
doc_id: CTW-REQ-001
title: CityTwin requirements
project: CityTwin
doc_type: Requirements
version: "0.8"
status: Draft
date: '2026-10-02'
author: Amish Chadha
license: CERN-OHL-S-2.0
revisions:
- version: "0.1"
  date: '2026-09-25'
  author: Amish Chadha
  change: "Initial scaffold"
- version: "0.2"
  date: '2026-09-25'
  author: Amish Chadha
  change: "First measurable requirements for TRL 2, with status against the concept estimates"
- version: "0.3"
  date: '2026-09-25'
  author: Amish Chadha
  change: "TRL 3 status from CTW-CAL-001; R12 and R17 redefined and R20 added per CTW-DDR-001; R1 restated for the pull paths (D11); reference rates from the sibling TRL 3 notes"
- version: "0.4"
  date: '2026-09-25'
  author: Amish Chadha
  change: "Recommendations accepted by Amish (DDR-002)"
- version: "0.5"
  date: '2026-10-01'
  author: Amish Chadha
  change: "Constructable design (CTW-DDR-003): R13 figures updated; R16 now not met ($778.00 against $750)"
- version: "0.6"
  date: '2026-10-01'
  author: Amish Chadha
  change: Budget treated as a value-engineering target
- version: "0.7"
  date: '2026-10-02'
  author: Amish Chadha
  change: R20 kept as a post-pilot target with outdoor sites only in permanent shade, as decided by Amish on 2026-10-02
- version: "0.8"
  date: '2026-10-02'
  author: Amish Chadha
  change: "CTW-DDR-003 noted as accepted by Amish on 2026-10-02; no requirement changed"
---

# CityTwin requirements

The decisions in CTW-DDR-001 and CTW-DDR-002 (decided by Amish, 2026-09-25: go with recommendation) set these targets; the constructable design of CTW-DDR-003 (2026-10-01, accepted by Amish on 2026-10-02) changes no target. R12 covers the pilot on a sheltered site at 0 to 35 °C air (D3, narrowed from 0 to 40 °C by DDR-002), the outdoor range is R20, R17 is a reported figure because the gateway is costed in TwinKit (D1), R10 is restated for the e-paper street kiosk, and R16 is reported against the $750 value-engineering target (a hypothetical control target, not a limit). The status column comes from the TRL 3 calculation note CTW-CAL-001 v0.3. Two requirements are **not met**: R18 (backup in the worst case, until TwinKit fits a larger pack) and R20 (street climate). R16 is **over the value-engineering target by $28.00** (the parts added to make the kiosk buildable; see the Value engineering section of CTW-DEC-001). R1 is **at risk**.

Table 1. Requirements.

| ID | Requirement | Target | Status (CTW-CAL-001) | Verification (TRL 4 or later) |
| --- | --- | --- | --- | --- |
| R1 | Ingest every node type in the smart city set | All 9: seven over LoRaWAN through TwinKit; PotholeLog segment files and DockHub hourly aggregates pulled by outbound HTTPS from the operators' servers (D11) | **At risk:** six LoRaWAN types met on paper; the pull paths are proposed but not agreed with PotholeLog and DockHub; CrossSafe has no LoRaWAN uplink defined | Interface agreement with each sibling repo |
| R2 | Capacity on one TwinKit gateway | 50 nodes or more and 10,000 records per day or more | Met on paper: 46 nodes send 5,616 uplinks a day with 0.61 % lost (collisions and downlink blanking); 10,000 a day lose 0.71 % | Packet capture on a live gateway |
| R3 | Accept only counts and levels | Each node type has a payload schema; any field outside it is rejected and logged; no images or audio stored | Met by design | Schema review; fuzz test of the decoder |
| R4 | Suppress small counts in public outputs | People and vehicle counts below 5 per hour (D6) published as "fewer than 5" | Met by design | Review of export code |
| R5 | No movement traces in public outputs | PotholeLog published per road segment only, no vehicle tracks or times finer than one day; DockHub per dock per hour, no card IDs | Met by design | Review of export code |
| R6 | Open data export | Hourly CSV and GeoJSON with a documented schema, under CC BY 4.0 (D7), pushed to a public host | Met by design: 7,128 rows, 0.86 MB of CSV a day | Sample export checked against the schema |
| R7 | One map for all node types | One layer per node type, node health, and an "as of" timestamp on every view | Met by design | Review of dashboard mock-up |
| R8 | Data freshness | Map and kiosk show data no older than 30 min in normal operation | Met on paper, thin margin: 25.9 min worst on the kiosk, 15.6 min on the web map | Timing log on a live system |
| R9 | Kiosk readable day and night | Readable in direct sun and at night at 1.5 m; key text cap height 7 mm or more | Met on paper: 41 px and 16.0 arcmin per capital; about 219 lx from the hood light dimmed to 0.3 W (1,459 lx at its full 2 W) | Mock-up viewed in sun and at night |
| R10 | Kiosk responds to a button (restated, CTW-DDR-002) | Street kiosk: press acknowledged within 0.5 s by the button's LED ring, which stays lit until the new image is drawn; selected layer shown within 25 s. Indoor LCD variant: selected layer within 5 s (the TRL 2 target) | Met on paper: LED ring in about 30 ms; layer in 19.8 s. The indoor LCD variant is not modeled at TRL 3 | Timed on a bench build |
| R11 | Accessible kiosk | Operable parts 380 to 1,220 mm above ground ([ADA forward reach](https://www.access-board.gov/ada/guides/chapter-3-operable-parts/)); overhang from the post no more than 305 mm between 685 and 2,030 mm ([protruding objects](https://www.access-board.gov/ada/guides/chapter-3-protruding-objects/)); same content on a web page that meets WCAG 2.1 AA, linked by QR code and short URL | Met on paper: buttons at 1,120 mm; overhang 200 mm (hood), 186.5 mm (cabinet with sun shield); web page not verifiable at TRL 3 | Accessibility audit of the web page and a site review |
| R12 | Pilot kiosk survives its climate (redefined, D3; range narrowed by CTW-DDR-002) | Sheltered or indoor site with no direct sun on the window; operate at 0 to 35 °C air; head IP54, cabinet IP55; panel within its 0 to 40 °C rating and the TwinKit pack within its 0 to 45 °C charge window | Met on paper: at 35 °C air the panel is at 35.1 °C (4.9 K margin) and the pack at 39.4 °C (5.6 K margin) | Temperature log in a climate chamber |
| R13 | Kiosk stands up to wind | 35 m/s gust with a factor of 1.5 without yield of post or anchors | Met on paper: post 26.6 MPa, 1.94 kN per anchor, with the sun shield | Structural design to the local code |
| R14 | Electrical safety | Mains only inside the locked cabinet, behind a 30 mA RCBO and a surge protector; only 12 V SELV in the head; all metal earthed | Met by design; 12 V peak 26.7 W on a 60 W supply | Inspection by a qualified electrician |
| R15 | Low running power | 15 W average or less including the TwinKit gateway | Met on paper: 9.2 W (81 kWh a year), with the hood light dimmed to 0.3 W | Energy meter on a bench build |
| R16 | Kiosk parts cost | Pilot kiosk (items 1 to 12, 14, 15, 20, 21) within the value-engineering target of $750 (hypothetical control target, not a limit; set in CTW-DDR-002); the outdoor sun shield (item 19) is reported separately | **Over the value-engineering target by $28.00:** estimated cost $778.00 after the parts added for construction (CTW-DDR-003); $808.00 with the outdoor sun shield. Savings worth trying are in CTW-DEC-001 | Priced BOM |
| R17 | Cost with gateway (redefined, D1) | Kiosk plus TwinKit gateway reported; the gateway is costed and budgeted in the TwinKit repo | Met on paper (reported): $1,068.00 | Priced BOM |
| R18 | Honest in an outage | Screen keeps the last image with its timestamp when power fails; gateway rides through 2 h on its backup pack | **Not met in the worst case:** 2.40 h with a new pack, 1.63 h aged at 0 °C (TWK-CAL-001); a pack of at least 1.84 Ah (now 1.5 Ah) would meet 2 h and has been requested from TwinKit (CTW-DDR-002); the e-paper keeps its image by design | Outage test |
| R19 | Secure by default | No inbound connections from the internet to the gateway; open data pushed and sibling data pulled by outbound connections only; no exposed ports or USB on the kiosk | Met by design | Security review |
| R20 | Street kiosk climate (new, target after the pilot, D3) | Operate from -20 °C to +45 °C air in full sun | **Not met:** panel about 79 °C in low sun and 45.1 °C shaded at 45 °C air; a heated, insulated panel bay needs 13.5 W at -20 °C (fitted only where the partner city has frost); behind the sun shield the pack stays under 45 °C in full sun up to 37.8 °C air, and is at 52.2 °C at 45 °C air | Chamber and field tests |

## Assumptions

- Node types and reporting rates follow the sibling TRL 3 calculation notes: CurbCount, HeatMap Node, FloodGauge and NoiseMap 96 uplinks a day; AirStreet 288; LoadZone 124 (100 state changes and 24 heartbeats). CrossSafe's hourly activation summary is a CityTwin assumption; CrossSafe has not defined a LoRaWAN uplink.
- Radio loss is calculated (CTW-CAL-001 section A) rather than assumed; the TRL 2 figure of about 3 % was a placeholder.
- The pilot kiosk (R12) stands on a sheltered site; the street range (R20) is the target after the pilot. Any outdoor site uses the cabinet sun shield and a shaded screen orientation as site rules (CTW-DDR-002), and is allowed only in permanent shade (decided by Amish, 2026-10-02, CTW-DEC-001); a panel rated above 40 °C is sought at TRL 4.
- 35 m/s design gust is an estimate for a first check; the local wind code governs any real installation.

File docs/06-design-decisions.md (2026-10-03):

---
doc_id: CTW-DEC-001
title: CityTwin design decisions register
project: CityTwin
doc_type: Design decisions register
version: "0.4"
status: Draft
date: '2026-10-02'
author: Amish Chadha
license: CERN-OHL-S-2.0
revisions:
- version: "0.1"
  date: '2026-10-01'
  author: Amish Chadha
  change: Register opened with the open decisions from the review note, the decision records and the build plan work
- version: "0.2"
  date: '2026-10-01'
  author: Amish Chadha
  change: Budget treated as a value-engineering target
- version: "0.3"
  date: '2026-10-02'
  author: Amish Chadha
  change: Amish approved the recommendations for open items 1 to 7 on 2026-10-02 (shield holes only where fitted, sheltered pilot near Irving, antenna walk test, languages, R20 kept as post-pilot target, pull format, CrossSafe uplink request); moved to decisions made
- version: "0.4"
  date: '2026-10-02'
  author: Amish Chadha
  change: "Design for construction (CTW-DDR-003, P1 to P14) accepted by Amish on 2026-10-02; moved from open for review to decisions made"
---

# CityTwin design decisions register

Every design decision still to be made, and every decision made, in one place. Each decision is argued in full in its decision record under `docs/decisions/`; this register is the index Amish works from. The build plan (`docs/05-build-plan.md`, CTW-BLD-001) describes the design as it stands and does not list open decisions.

## Open decisions

None. All open decisions were decided on 2026-10-02.

## To confirm when parts are bought

*Table 2. Items to confirm against the chosen part.*

| # | What to confirm | Why it matters | Source |
| --- | --- | --- | --- |
| 1 | The cabinet comes with a removable mounting plate of about 340 x 390 mm on studs that stand it at least 10 mm off the back wall, and a lockable door on the 360 x 460 mm face | The rails, the cabinet screws behind the plate and the 25 mm cable hole above the plate are placed for this | CTW-DDR-003, P9 |
| 2 | The e-paper panel's outline (210 x 290 x 7 mm assumed) and where its flat cable leaves the panel | Sets the foam gasket, the carrier's ribbon slot and the driver board position | CTW-DDR-003, P4 |
| 3 | The M8 steel flush rivet nuts' grip range covers the 4 mm post wall with its coating, and their countersink size | The head and cabinet screws depend on them | CTW-DDR-003, P1 |
| 4 | The buttons' LED rings run from 5 V or 12 V, and their nut size fits beside the notice plate | Sets the LED driver wiring and the clearance below the notice plate | CTW-DDR-003, P5, P6 |
| 5 | TwinKit fits a backup pack of at least 1.84 Ah for cabinet installs (now 1.5 Ah); until then R18 is not met in the worst case | The outage ride-through of 2 h | CTW-DDR-002, N3 |
| 6 | The hood light's LED strip and dusk sensor work from the 12 V supply through the LED driver, dimmed to about 0.3 W | Night lighting (R9) and running power (R15) | CTW-DDR-002, N6 |
| 7 | The anchor design resistance (10 kN per M16 anchor assumed) and the footing, from a structural design to the local code | Wind (R13) and the safety of a kiosk of about 64 kg beside a walkway | CTW-CAL-001, section H |

## Value engineering

Value-engineering target: USD 750 (a hypothetical control target, not a limit). Estimated cost of the constructable design: USD 778 for the pilot kiosk (USD 28 over the target; the pilot site is sheltered, so no sun shield or frost heater, decided 2026-10-02); USD 808 with the outdoor sun shield, and USD 1,068 with the TwinKit gateway, which is costed in TwinKit.

- **Main cost drivers:** the parts added to make the kiosk buildable (display carrier USD 8, fixings USD 22, and USD 13 more for the head's converter, LED driver and terminal block, less USD 4 moved out of another item); the outdoor sun shield (USD 30), reported separately.
- **Savings worth trying:** a lower-cost cabinet; dropping the real-time clock; checking prices at purchase, since the figures are indicative.

## Decisions made

*Table 3. Decisions made, with the record that argues each one.*

| Date | Decision | Decided by | Record |
| --- | --- | --- | --- |
| 2026-09-25 | TRL 2 review items D1 to D11: budget covers the kiosk only; color e-paper with an indoor LCD variant; sheltered pilot; gateway in the kiosk cabinet; mains power; 5 per hour small-count threshold and two years of raw data; CC BY 4.0; buttons; 46-node reference neighborhood; one-way publishing; outbound pulls for PotholeLog and DockHub | Amish: "i accept all your recommendations, go with them across all repos." | [CTW-DDR-001](decisions/0001-trl2-review-decisions.md), [CTW-DDR-002](decisions/0002-recommendations-accepted.md) |
| 2026-09-25 | N1 to N6: `budget_usd` $750; R10 restated (LED ring within 0.5 s, layer within 25 s); larger TwinKit pack requested; cabinet sun shield and shaded screen as outdoor site rules, heater only for a frost city; pilot range 0 to 35 °C air; hood light dimmed to about 0.3 W | Amish, same instruction | [CTW-DDR-002](decisions/0002-recommendations-accepted.md) |
| 2026-10-01 | Design for construction, P1 to P14: rivet nuts in the post for the head and cabinet; folded head tray with a removable front panel; window bonded with glazing tape; display carrier on studs; 5 V converter, LED driver and terminal block in the head; button, notice plate and hood fixings; mounting plate in the cabinet; grommeted cable holes; conduit hole and gland; vent hole for galvanizing; antenna bracket plate; shield on standoffs with a thumb-screw back panel | Made under Amish's 2026-09-30 instruction to make the design physically buildable ("If you are realising that the design cannot be built as per concept - fix the design assumptions to match and be physically feasible as you draw the illustrations."); the changes themselves were accepted on 2026-10-02 (below) | [CTW-DDR-003](decisions/0003-design-for-construction.md) |
| 2026-10-02 | Sun shield standoff holes: option (a), drilled only in cabinets that get the shield, so the sheltered pilot cabinet keeps its unbroken IP55 sides | Amish: "i approve your recommendations for all 555 open decisions." | [CTW-DDR-003](decisions/0003-design-for-construction.md), A2 |
| 2026-10-02 | First partner and pilot site: a city within easy reach of Irving, Texas, with an active open-data program, the kiosk in a sheltered public lobby such as a library or transit center; with a sheltered site the frost heater is not fitted. The city is chosen as the first candidate to approach, not yet agreed | Amish: "i approve your recommendations for all 555 open decisions." | [CTW-DDR-001](decisions/0001-trl2-review-decisions.md), O1; [CTW-DDR-002](decisions/0002-recommendations-accepted.md) |
| 2026-10-02 | Antenna: keep the post-top antenna at 2.38 m for the pilot and run a coverage walk test from the site at TRL 4; if nodes in the reference neighborhood fall short, move to a rooftop gateway, not a taller mast | Amish: "i approve your recommendations for all 555 open decisions." | [CTW-DDR-002](decisions/0002-recommendations-accepted.md), Q1 |
| 2026-10-02 | Languages: English plus the partner city's most widely spoken other language in its own script, with a QR code and a phone or text number on the notice plate for questions and fault reports; refined with the partner in co-design | Amish: "i approve your recommendations for all 555 open decisions." | [CTW-DDR-002](decisions/0002-recommendations-accepted.md), Q2 |
| 2026-10-02 | Street climate (R20): kept as a post-pilot target; outdoor sites only in permanent shade with the sun shield; a panel rated above 40 °C is sought at TRL 4, and the heated bay is fitted only for a frost city | Amish: "i approve your recommendations for all 555 open decisions." | CTW-PRC-001, open questions; CTW-REQ-001, R20 |
| 2026-10-02 | Pull paths: the outbound pull already decided (D11), with daily CSV files on a fixed HTTPS address at each operator, a published column list and a version field; the same format to be agreed in PotholeLog (its open item 6) | Amish: "i approve your recommendations for all 555 open decisions." | [CTW-DDR-001](decisions/0001-trl2-review-decisions.md), D11 |
| 2026-10-02 | CrossSafe uplink: ask CrossSafe to add an hourly LoRaWAN summary uplink from one side of the crossing; CityTwin shows no CrossSafe layer until it exists | Amish: "i approve your recommendations for all 555 open decisions." | CTW-REQ-001, R1 |
| 2026-10-02 | Design for construction accepted: the changes P1 to P14, as made | Amish: "APPROVED: Design-for-construction changes in 10 repos (CityTwin, CoolShade, PalletPilot, Heliolite, PotholeLog, EarthPress, ReadyKit, CellCheck, CargoMule and ThermaCart)" | [CTW-DDR-003](decisions/0003-design-for-construction.md), Table 1 |

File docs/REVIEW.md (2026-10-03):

# Review note: CityTwin

## Session 2026-10-01: design for construction and the prototype build plan

On 2026-09-30 Amish approved the build plan format and asked for it across all repos, with open decisions kept in a separate register, and wrote: "If you are realising that the design cannot be built as per concept - fix the design assumptions to match and be physically feasible as you draw the illustrations." Kit 1.7.0 was installed (`.kit/`, `.claude/commands/`, root `CLAUDE.md`) and `/build-plan` was carried out. Nothing was built or tested; TRL stays 3.

### Design changes made for construction (CTW-DDR-003, Draft, open for Amish's review)

Made under Amish's 2026-09-30 instruction to make the design physically buildable; open for his review.

| # | Change |
| --- | --- |
| P1 | Eight M8 flush steel rivet nuts in the post; the head tray and the cabinet each held by four M8 screws with 30 mm washers from inside |
| P2 | Display head is a folded 2 mm tray with a 15 mm return flange, closed by a removable 2 mm front panel on twelve M4 tamper-resistant screws into rivet nuts, with a gasket |
| P3 | Window bonded inside the front panel with 1 mm glazing tape on its 8 mm lap |
| P4 | New display carrier (BOM 20) on eight clinch studs and 15 mm spacers presses the e-paper panel onto a 1 mm foam gasket and carries the driver board and controller |
| P5 | 12 V to 5 V converter, 4-channel LED driver and a pluggable fused terminal block added to BOM item 6 ($42.00 to $55.00) |
| P6 | Button holes 19.2 mm, bezel outside, nut inside |
| P7 | Notice plate held by four M4 tamper-resistant screws with nyloc nuts |
| P8 | Hood is folded 1.5 mm sheet on four M5 screws into rivet nuts in the head top; LED strip on an angle behind the lip; LED cable through a grommet in the front panel |
| P9 | DIN rails on the cabinet's mounting plate on 10 mm standoffs |
| P10 | 25 mm grommeted cable holes through post and cabinet (735 mm) and post and head (1,380 mm), replacing a slot that met a solid wall |
| P11 | 40 mm conduit hole in the base plate and a conduit gland in the cabinet floor |
| P12 | Anchor holes, washers and nuts; 25 mm vent and drain hole under the post so it can be galvanized |
| P13 | Antenna bracket is a 60 x 60 x 6 mm plate screwed to the cap |
| P14 | Sun shield on four 25 mm standoffs through the cabinet sides; separate back panel on four thumb screws |
| | New BOM line 21 (fixings, tapes and gaskets, $22.00); line 15 repriced to $26.00 |

The model runs 244 constructability checks (`python cad/src/model.py --check`), all passing: no overlaps, 50 contacts, 10 clearances.

### Key results (CTW-CAL-001 v0.3)

- **R16 is now over the value-engineering target by $28.00:** the estimated cost of the pilot kiosk is $778.00 against the $750 target (a hypothetical control target); $808.00 with the outdoor sun shield; $1,068.00 with the TwinKit gateway. `budget_usd` was not changed.
- Mass 63.5 kg with the sun shield (was 60.1 kg). Wind: 821 N, post 26.6 MPa, 1.94 kN per anchor (R13 still met on paper).
- Requirement status: 2 not met (R18, R20), 1 over the value-engineering target (R16), 1 at risk (R1), 9 met on paper, 7 met by design.
- Thermal, power, radio, timing and legibility are unchanged.

### What was made

- `cad/src/model.py`: constructable model with `build_components()`, the checks and STEP and STL exports (`cad/step/`, `cad/stl/`, four groups).
- `cad/src/sheets.py` and `cad/drawings/CTW-DWG-001` at Rev P4.
- `cad/src/build_plan_media.py`: overview, 11 making sketches (`cad/drawings/CTW-DWG-101` to `111`), 10 joint pictures (six of them true sections to scale), 16 step pictures, post and front panel hole layouts and a wiring diagram, in `docs/05-build-plan/`.
- `docs/05-build-plan.md` (CTW-BLD-001 v0.1) and `docs/06-design-decisions.md` (CTW-DEC-001 v0.1); `docs/decisions/0003-design-for-construction.md` (CTW-DDR-003 v0.1).
- Updated: `bom/bom.csv` (21 lines), `bom/bom-notes.md`, `docs/04-calcs/sizing.py`, `results.csv` and CTW-CAL-001 v0.3, CTW-REQ-001 v0.5, CTW-PRC-001 v0.5, CTW-PRB-001 v0.5, `README.md` (links line, components, figures, "Building the prototype"), `project.yaml` (`design_state: constructable`, evidence), concept media in `media/` regenerated from the new model, and the PDFs in `docs/pdf/`.

### Proposed, awaiting Amish (also in CTW-DEC-001)

1. **Shield standoff holes (A2).** Drill only kiosks that get the shield (recommended), or every cabinet with sealed blanking screws.
2. Still open from earlier: first partner city (O1), antenna height (Q1), languages and fault reporting (Q2), street climate panel (R20), PotholeLog and DockHub pull formats, CrossSafe uplink.

### Stale on Amish's Mac

The photoreal renders (`media/render-hero.png`, `media/render-detail.png`), `media/card.png` and `media/social-preview.png` show the concept head, hood and shield; the shield's standoffs and separate back panel, the front panel screws and the thinner hood edge now differ. They were not regenerated here (`media/render-hero.png` is also missing from this copy).

### Safety

No change to the safety case. The plan adds safety stops for lifting the post, mains work (electrician only), first switch-on, the gateway pack fuse, work at the post top, 12 V to the head, and leaving the kiosk unattended. The hood corners at head height are now specified as rounded to at least 10 mm.

### Recommended next step

Amish's review of CTW-DDR-003 and decision A2; the register's Value engineering section holds the $750 target, the $778.00 estimate and the savings worth trying. TRL 4 (building and testing to CTW-BLD-001) remains on hold.

## Session 2026-09-26: sources strengthened

Amish asked on 2026-09-26 to "Fix the weaker sources." README.md sections Concept rationale, Burning platform, Where it could be used and What sparked the idea were checked; every kept link was fetched and confirmed against its claim.

| Where | Old source | New source |
| --- | --- | --- |
| What sparked the idea (Amsterdam sensor register) | Cities Today (trade press) with the Sensorenregister site | The regulation itself, Verordening meldingsplicht sensoren ([Gemeenteblad 2021, 368183](https://zoek.officielebekendmakingen.nl/gmb-2021-368183.html)), with the Sensorenregister site |

The paragraph now states only what the regulation supports: in force December 1, 2021, advance reporting of what data a sensor collects, exemptions for private individuals and police or public order use, six months for sensors already in place, and a city register of the reports. The claims that the register map shows owner and personal data processing and that the city could remove unregistered sensors at the owner's expense rested on Cities Today alone and were removed. The inspiration event is unchanged; its line in INSPIRATIONS.md now names the Gemeenteblad source. docs/01-problem.md did not cite Cities Today and was not changed. No budget change.

## Session 2026-09-25: recommendations accepted

On 2026-09-25 Amish wrote, in chat: "i accept all your recommendations, go with them across all repos." Every item in this note and in CTW-DDR-001 that carried a recommendation is now **decided by Amish, 2026-09-25: go with recommendation**, recorded in `docs/decisions/0002-recommendations-accepted.md` (CTW-DDR-002 v0.1). Items with no recommendation stay "Proposed, awaiting Amish". Nothing past TRL 3 was done.

### Decisions applied and what changed

| Item | Decision | Before | After |
| --- | --- | --- | --- |
| D1 to D11 (CTW-DDR-001) | Budget scope, color e-paper, sheltered pilot, gateway in the cabinet, mains power, privacy settings, CC BY 4.0, buttons, reference neighborhood, one-way publishing, outbound pulls | Adopted for TRL 3, open for review | Decided; status wording in CTW-DDR-001 v0.2, CTW-PRB-001 v0.4, CTW-PRC-001 v0.4, CTW-REQ-001 v0.4 |
| N1 budget figure | Recommended $750 | `budget_usd` $600; R16 not met ($139.00 over) | `budget_usd` $750; R16 met on paper ($11.00 under) |
| N2 R10 | Option (a) street, (b) indoor LCD | Layer within 5 s; 19.8 s, not met | LED ring within 0.5 s (about 30 ms) and layer within 25 s (19.8 s), met on paper; the indoor LCD variant keeps 5 s (not modeled) |
| N3 R18 | Option (b), larger TwinKit pack | Pack not sized | At least 1.84 Ah needed against 1.5 Ah; requested from TwinKit; R18 still not met |
| N4 R20 and cabinet | Cabinet sun shield and shaded screen as site rules; heater only for a frost city | Cabinet 18.8 K over ambient in sun; no shield | New BOM item 19 (1.5 mm aluminum, 25 mm air gap, $30.00) in the model, STEP, STL, CTW-DWG-001 Rev P2 and media; cabinet 7.2 K over ambient in sun behind the shield, pack under 45 °C up to 37.8 °C air; R20 still not met |
| N5 R12 margin | Pilot range 0 to 35 °C air | 0 to 40 °C; panel 40.1 °C, pack 0.6 K margin; at risk | Panel 35.1 °C (4.9 K margin), pack 39.4 °C (5.6 K margin); met on paper |
| N6 hood light | Dim to about 0.3 W | 2 W, 1,459 lx; mains 10.2 W, 90 kWh a year | 0.3 W, 219 lx; mains 9.2 W, 81 kWh a year |

Knock-on figures: the sun shield adds 1.86 kg and 35 N of gust load, so post stress rises from 26.2 to 26.9 MPa, anchor tension from 1.92 to 1.97 kN and mass from 58.2 to 60.1 kg; all still met. The outdoor kiosk with the shield costs $769.00, $19.00 over `budget_usd`; R16 is set on the sheltered pilot kiosk. The pitch and problem lines were not reworded because no rewording was recommended.

Files changed: `project.yaml` (`budget_usd`), `README.md` (budget line, concept numbers, components, BOM line, safety, "What sparked the idea"), `docs/01-problem.md` (v0.4), `docs/02-concept.md` (v0.4), `docs/03-requirements.md` (v0.4), `docs/04-calcs/01-sizing.md` (CTW-CAL-001 v0.2), `docs/04-calcs/sizing.py` and `results.csv`, `docs/decisions/0001-trl2-review-decisions.md` (v0.2), new `docs/decisions/0002-recommendations-accepted.md`, `bom/bom.csv` (19 lines) and `bom/bom-notes.md`, `cad/src/model.py`, `cad/step/`, `cad/stl/`, `cad/src/sheets.py` and `cad/drawings/CTW-DWG-001` (Rev P2), `cad/src/concept_media.py` and all of `media/`, and the PDFs in `docs/pdf/`. All generated files were rebuilt, so none still shows the old site address.

"What sparked the idea" in `README.md` no longer describes how the portfolio was assembled. It now traces the idea to Amsterdam's mandatory register of sensors in public space (in force December 2021), cited to Cities Today and the city's register.

### Requirement status (CTW-CAL-001 v0.2)

2 not met, 1 at risk, 10 met on paper, 7 met by design (before: 4 not met, 2 at risk, 7 met on paper, 7 met by design).

| ID | Status | Key number |
| --- | --- | --- |
| R18 Outage ride-through | **Not met** (worst case) | 1.63 h aged at 0 °C against 2 h; needs a pack of at least 1.84 Ah from TwinKit |
| R20 Street climate | **Not met** | Panel about 79 °C in low sun and 45.1 °C shaded at 45 °C air; pack 52.2 °C at 45 °C behind the sun shield; heater 13.5 W at -20 °C |
| R1 Ingest every type | At risk | PotholeLog and DockHub pull formats not agreed; CrossSafe has no LoRaWAN uplink |
| R2, R8 to R13, R15 to R17 | Met on paper | 0.61 % lost; 25.9 min data age; 219 lx; LED ring 30 ms and layer 19.8 s; panel 35.1 °C at 35 °C; 26.9 MPa; 9.2 W; $739.00 against $750 |
| R3 to R7, R14, R19 | Met by design | |

### Still awaiting Amish

1. **O1, first partner city or neighborhood** for co-design and a pilot site. No recommendation was made. Proposed, awaiting Amish. This also decides whether the frost heater is fitted (N4).
2. Open questions without a recommendation, kept in CTW-PRC-001: antenna height for the reference neighborhood with the gateway in the cabinet, and the kiosk's languages and fault reporting (for co-design with the O1 partner).

### Cross-repo actions

- **TwinKit:** fit a backup pack of at least 1.84 Ah (now 1.5 Ah) for cabinet installs, so R18 is met with an aged pack at 0 °C (N3). TwinKit's review also asked for a street cabinet thermal check: this note gives 4.4 K rise in shade, 18.7 K in sun, 7.2 K in sun behind CityTwin's sun shield. TwinKit not edited.
- **PotholeLog:** agree the published daily segment file format and host that the CityTwin gateway pulls by outbound HTTPS (D11). Not edited.
- **DockHub:** agree per-dock hourly aggregates published by its back end for the CityTwin pull (D11). Not edited.
- **CrossSafe:** define a LoRaWAN uplink (hourly summary assumed here) so CityTwin's CrossSafe layer has an interface (R1). Not edited.
- **LoadZone and TwinKit:** class C downlink support on TwinKit's network server for LoadZone's sign, as noted in the TRL 3 session. Not edited.

### TRL 4

TRL 4 remains on hold by Amish's instruction. `trl: 3` and `trl_target: 3` are unchanged. Decided but on hold because they are TRL 4 work: fitting and testing the frost heater, building the indoor LCD and solar variants, and every bench build, button timing, climate chamber, backup and outage test. No build, test, purchasing, PCB or firmware material was created.

## Session 2026-09-25: TRL 3

On 2026-09-25 Amish asked for this batch of repos to be taken through the usual process with the instruction "you know the drill, nothing gets past TRL 3". He has not reviewed this repo's TRL 2 items one by one, so every item that carried a recommendation is adopted as recommended for TRL 3 under Amish's 2026-09-25 instruction, open for his review. Nothing here is recorded as decided or approved by Amish. This session ran `/advance-trl3` on that basis and stopped at TRL 3.

### What was done

- `docs/decisions/0001-trl2-review-decisions.md` (CTW-DDR-001 v0.1, status proposed): D1 to D10 adopted as recommended for TRL 3, open for Amish's review; D11 (pull paths for PotholeLog and DockHub) proposed in this session; O1 left open.
- `docs/04-calcs/01-sizing.md` (CTW-CAL-001 v0.1), `docs/04-calcs/sizing.py` and `docs/04-calcs/results.csv`: radio load and loss with the sibling repos' TRL 3 rates and LoadZone downlinks, storage and export, data age and button timing, legibility, night light and hood shading, accessibility geometry, head and cabinet thermal with a heater study, power and supply sizing, wind, weld, anchors and mass, backup, and cost, with a status for every requirement. The script imports the model's parameters and part volumes, reads the BOM and `project.yaml`, and prints every quoted number with a tag.
- `cad/src/model.py`: parametric build123d kiosk (base plate and anchors, post with cable entry, head with window, button holes and vents, window, e-paper, controller, buttons, notice plate, hood with light, cabinet with two TS35 rails, RCBO and SPD, 12 V supply, TwinKit gateway laid out as in TWK-DWG-001, antenna, conduit). Exports `cad/step/` and `cad/stl/` for `citytwin-kiosk-assembly`, `kiosk-head`, `services-cabinet` and `post-and-base`. A clash check finds only the intended wall penetrations of the conduit and cable entry.
- `cad/src/sheets.py` and `cad/drawings/CTW-DWG-001.svg`, `.pdf`, `.png`: general arrangement at Rev P1, 1:20, marked "CONCEPT, NOT FOR FABRICATION" and "PRELIMINARY, NOT FOR FABRICATION". CTW-DWG-001 was free because the concept blueprint is CTW-DWG-010.
- `bom/bom.csv` (18 lines, all priced with a supplier or supplier type) and `bom/bom-notes.md`. TwinKit now at its TRL 3 price, $290.00.
- `cad/src/concept_media.py` now builds from the model; all of `media/` re-rendered (hero, blueprint, cutaway, exploded, flow, `model.glb`, `viewer.html`) and every image checked; no `media/_views*` folders remain.
- CTW-PRB-001, CTW-PRC-001 and CTW-REQ-001 revised to v0.3; `README.md` (TRL badge and line, budget line, links, concept numbers, components, safety; the required sections keep their order and wording) and `project.yaml` (`trl: 3`, `trl_target: 3`, evidence list) updated. PDFs rebuilt in `docs/pdf/`.

### Requirement status (CTW-CAL-001, Table 2)

4 not met, 2 at risk, 7 met on paper, 7 met by design (R11's web page is not verifiable at TRL 3).

| ID | Status | Key number |
| --- | --- | --- |
| R10 Button response | **Not met** | 19.8 s against 5 s (0.79 s transfer plus 19 s full refresh) |
| R16 Kiosk cost | **Not met** | $739.00 against $600 (`budget_usd`); $11.00 under the recommended $750 |
| R18 Outage ride-through | **Not met** (worst case) | TwinKit backup 2.40 h new, 1.63 h aged at 0 °C, against 2 h |
| R20 Street climate (new) | **Not met** | Panel about 79 °C in low sun at 45 °C air; 13.5 W to hold an insulated panel bay at 0 °C in -20 °C air |
| R1 Ingest every type | At risk | Six LoRaWAN types on paper; PotholeLog and DockHub pull paths not agreed; CrossSafe has no LoRaWAN uplink |
| R12 Pilot climate (redefined) | At risk | Panel 40.1 °C at 40 °C air; cabinet pack 0.6 K under its 45 °C charge limit |
| R2, R8, R9, R11, R13, R15, R17 | Met on paper | 5,616 uplinks a day, 0.61 % lost; 25.9 min data age; 41 px capitals; 200 mm overhang; 26.2 MPa post, 1.92 kN per anchor; 10.2 W; $1,029.00 reported |
| R3 to R7, R14, R19 | Met by design | 7,128 export rows a day; 12 V peak 26.7 W on 60 W |

Corrections to TRL 2 figures: 5,616 uplinks a day, not 4,896 (LoadZone sends 124 a day, not 64); radio loss 0.61 %, not an assumed 3 %; storage 2.89 GB a year raw at TwinKit's conservative row size, not 350 MB; export 7,128 rows a day once PotholeLog segments are counted, not 1,100; power 10.2 W, not 9 W; post stress 26.2 MPa with post drag and the 1.5 factor, not 12 MPa; mass 58.2 kg, not 55 kg; gateway $290.00, not $285. The backup pack now sits inside TwinKit's UPS module, as TwinKit draws it.

### Decisions recorded (CTW-DDR-001)

Adopted as recommended for TRL 3 under Amish's 2026-09-25 instruction, open for his review (now **decided by Amish, 2026-09-25: go with recommendation**, see CTW-DDR-002): D1 budget option (b), the budget covers the kiosk and the gateway is costed in TwinKit (R17 redefined; `budget_usd` unchanged at $600, $750 recorded as awaiting Amish); D2 color e-paper with an indoor LCD variant; D3 sheltered or indoor pilot and a heater study at TRL 3 (R12 redefined to the pilot, R20 added); D4 gateway in the kiosk cabinet; D5 mains power with a solar head-only variant; D6 small-count threshold 5 per hour and two years of raw data; D7 CC BY 4.0; D8 buttons; D9 the 46-node reference neighborhood with the sibling TRL 3 rates; D10 one-way publishing and privacy rules at the gateway. No reworded pitch or problem line was recommended, so `project.yaml` and `README.md` keep the existing wording.

### Still awaiting Amish

Status update: items 2 to 7 and the hood light suggestion below are now decided by Amish, 2026-09-25: go with recommendation (session "recommendations accepted" above). Item 1 stays Proposed, awaiting Amish.

1. **O1, first partner city or neighborhood** for co-design and a pilot site. No recommendation was made.
2. **Budget figure.** `budget_usd` stays $600; $750 is recommended (D1). The kiosk at $739.00 fits $750. **Decided by Amish, 2026-09-25: go with recommendation** (CTW-DDR-002).
3. **New, D11 pull paths.** The gateway fetches PotholeLog's published segment files and DockHub's hourly aggregates by outbound HTTPS. Recommendation: adopt, and agree formats with both repos. Used for sizing; not agreed. **Decided by Amish, 2026-09-25: go with recommendation** (CTW-DDR-002).
4. **New, R10.** Options: (a) restate R10 as "press acknowledged within 0.5 s by the LED ring and a first on-screen cue; layer shown within 25 s"; (b) keep 5 s and fit an LCD in the indoor variant only; (c) a smaller monochrome status panel for instant feedback. Recommendation: (a) for the street kiosk and (b) indoors. Not applied. **Decided by Amish, 2026-09-25: go with recommendation** (CTW-DDR-002).
5. **New, R18.** Options: (a) restate R18 at 1.5 h; (b) ask TwinKit for a larger pack in cabinet installs; (c) keep 2 h and accept not met. Recommendation: (b), since winter cold in a street cabinet shortens the runtime further. Not applied. **Decided by Amish, 2026-09-25: go with recommendation** (CTW-DDR-002).
6. **New, R20 and the cabinet.** Options for a street kiosk: a heated, insulated panel bay (13.5 W at -20 °C, not costed), a north-facing or shaded screen, a ventilated sun shield on the cabinet, or a wider-range panel if one exists. Recommendation: a sun shield on the cabinet and a shaded screen orientation as site rules for any outdoor pilot; a heater only if the partner city has frost. Not applied. **Decided by Amish, 2026-09-25: go with recommendation** (CTW-DDR-002).
7. **New, R12 margin.** At 40 °C air the panel and pack have no margin. Recommendation: define the pilot range as 0 to 35 °C air. Not applied. **Decided by Amish, 2026-09-25: go with recommendation** (CTW-DDR-002).

Suggestion only, not in the repo: dim the hood light to about 0.3 W (200 lx is enough), which would cut 0.9 W from the average. **Decided by Amish, 2026-09-25: go with recommendation** (CTW-DDR-002).

### Cross-repo consistency

- **TwinKit (TRL 3):** gateway $290.00, 6.41 W, 20.6 W peak, 294 mm of rail, backup 2.40 h and 1.63 h worst, processor 69.1 °C at 40 °C, loss 1.02 % at 14,400 uplinks a day; all used as published. TwinKit's review asked for a separate thermal check of the street cabinet: this note finds the cabinet 4.4 K above ambient in shade and 18.8 K in sun, so TwinKit's 0 to 40 °C rating and the pack's 45 °C charge limit hold only on a sheltered site. The TwinKit whip is replaced by a coax lead to a post-top antenna; TwinKit's SMA bulkhead allows this. TwinKit's network server must support LoRaWAN class C for LoadZone's sign (LoadZone O5). TwinKit not edited.
- **PotholeLog (TRL 3):** uploads 112 kB a day per vehicle to the fleet operator's server and asked how CityTwin would receive the files given no inbound connections; D11 answers with an outbound pull. A publication date on a daily segment aggregate is compatible with PotholeLog's R13 if pass times stay unpublished. PotholeLog not edited.
- **DockHub (TRL 3):** syncs over LTE-M to its own back end and logs 1.28 kB a day; CityTwin assumes DockHub's back end publishes per-dock hourly aggregates for D11. DockHub names TwinKit only as a later suggestion. Not edited.
- **LoadZone (TRL 3):** 124 uplinks a day per puck of 12 B, and about 200 downlinks a day per sign; the downlinks cost 0.23 % of the gateway's receive time with six signs. No conflict.
- **CrossSafe (TRL 3), conflict:** its radio runs LoRa point to point between the two sides and no LoRaWAN uplink is defined, so CityTwin's CrossSafe layer has no interface yet. Noted here; CrossSafe not edited.
- **FloodGauge, CurbCount, HeatMap Node, AirStreet, NoiseMap (TRL 3):** rates and payloads as in their notes; NoiseMap's note confirms the 96 uplinks a day CityTwin assumed. FloodGauge's event mode is covered in the storm peak hour (0.94 % loss). CurbCount's and LoadZone's US915 payload packing does not change CityTwin's load.
- FieldNode, CellGuard, MotionCore, ThermaCart and CalRig are not used by CityTwin.

### Safety concerns

- Mains voltage in the cabinet: electrician installation, 30 mA RCBO, surge protection, earthing of all metal parts, locked door, only 12 V SELV in the head.
- LiFePO4 backup pack in a sealed steel cabinet: in sun the cabinet air reaches about 64 °C at 45 °C ambient, far above the pack's charge limit, and in frost it cannot charge. The UPS lockout must never be defeated; site the pilot out of direct sun.
- A 58 kg post beside a walkway: the footing and anchors need a structural design to the local code; vehicle impact is not covered by this note. The hood corners overhang the post by 200 mm at head height: round and pad them.
- Privacy: the schema check and small-count suppression at the gateway need review; outbound pulls must fetch only published aggregates, never raw PotholeLog tracks or DockHub logs.
- Over-reliance: CityTwin is not a flood or emergency warning system.

### Gaps and notes

- Citations: none were flagged as unchecked at TRL 2. The Access Board protruding-objects guide (685 to 2,030 mm, 305 mm overhang on posts) was checked by WebFetch on 2026-09-25 and is now cited. The Waveshare refresh time and temperature range were not re-fetched. WebSearch was not used.
- Assumptions only tests can settle: film coefficients and absorptance, panel heating through the window, controller and hood light power, supply efficiency at light load, anchor resistance, and bought-in masses.
- The kit's cutaway cuts on a Y plane near the parts' mean; as at TRL 2, `concept_media.py` makes its own X-plane section on the kiosk centerline with the kit's renderer. It works for this model without shifting it.
- In `media/exploded.png` the callouts for the small parts 7, 11 and 12 partly cover them.
- Existing material beyond TRL 3: `build-log/README.md` (scaffold) is present, untouched and not extended. `electronics/` and `firmware/` are empty. No test, build or firmware material was created.

### Recommended next step

TRL 4 is on hold by Amish's instruction; this repo stops at TRL 3. The next step is Amish's review of CTW-DDR-001 (D1 to D11) and a choice on items 1 to 7 above, plus interface agreements with PotholeLog, DockHub and CrossSafe. For the record only, TRL 4 would need: a bench build of the kiosk head and cabinet with a TwinKit gateway; a lab test report (TST, `environment: lab`) covering button-to-layer timing, panel and cabinet temperatures in a climate chamber with a sun lamp, mains power draw, backup runtime with a cold pack, and ingest of recorded sibling payloads through the schema check; and build log entries. None of this has been started.

## Session 2026-09-25: /populate to a strong TRL 2

### What was done

- `docs/01-problem.md` (CTW-PRB-001 v0.2): problem, trust evidence, prior work (Sentilo, Civil IoT Taiwan, OGC SensorThings API, DTPR, AirQo), users, operating environment, a proposed 46-node reference neighborhood, constraints, out of scope, open questions; co-design checklist kept.
- `docs/03-requirements.md` (CTW-REQ-001 v0.2): 19 measurable requirements with targets and a status column against the concept estimates.
- `docs/02-concept.md` (CTW-PRC-001 v0.2): how it works (collect, check, store, privacy rules, publish, show), 18 numbered components, data load and kiosk estimates, design choices, safety section, open questions.
- `cad/src/concept_media.py`: massing model of the public kiosk (post, base plate, display head, window, e-paper, controller, buttons, notice plate, hood, services cabinet with mains protection, 12 V supply and TwinKit gateway, antenna, conduit) in street context with a 1.75 m figure. The cutaway uses a custom section on the kiosk centerline, because the kit's default Y cut would slice across the screen instead of through the layers.
- `media/`: `hero.png`, `concept-blueprint.png`, `.pdf` and `.svg`, `exploded.png` with callouts 1 to 15, `cutaway.png`, `flow.png` (data flow in records per day, estimates), `model.glb` and `viewer.html`.
- `bom/bom.csv`: 18 lines, numbered to match the exploded view (16 to 18 are software and documents with no callout); `bom/bom-notes.md` explains what is in and out of each cost.
- `README.md`: hero image and links line, expanded concept rationale, burning platform, where it could be used, what sparked the idea, concept, components and safety.
- `docs/pdf/`: branded PDFs of the three controlled documents.
- `project.yaml`: unchanged. The pitch and problem still match the concept.

### Key results (estimates, to be checked at TRL 3)

| Quantity | Estimate | Requirement |
| --- | --- | --- |
| Reference neighborhood | 46 LoRaWAN nodes, about 4,900 records per day | R2 met (50 nodes, 10,000 per day) |
| Radio airtime | about 1 % of one channel, about 0.13 % over 8 | R2 met |
| Storage | about 350 MB per year | |
| Worst data age on screen | about 25 min | R8 met, thin margin (30 min) |
| Button to new layer | about 20 s | **R10 not met** (5 s) |
| Display operating range | 0 to 40 °C (maker's manual) | **R12 not met** (-20 to +45 °C) |
| Kiosk and gateway power | about 9 W, about 75 kWh per year | R15 met (15 W) |
| Post stress at 35 m/s gust | about 12 MPa | R13 met |
| Kiosk mass | about 55 kg | |
| Kiosk parts cost | about $740 | **R16 not met** ($600) |
| Kiosk plus TwinKit gateway | about $1,025 | **R17 not met** ($600 `budget_usd`) |

Requirements not met or at risk:

- **R10 not met:** the color e-paper has no partial refresh and takes about 19 s for a full refresh.
- **R12 not met:** the panel is rated 0 to 40 °C; a sunlit head in a 45 °C day or a Canadian winter falls outside that.
- **R16 and R17 not met:** kiosk about $740, about $1,025 with the gateway, against $600.
- **R1 at risk:** PotholeLog and DockHub upload paths into CityTwin are not defined in those repos.

### Proposed, awaiting Amish

Status update: items 1 to 9 are decided by Amish, 2026-09-25: go with recommendation (CTW-DDR-001 v0.2 D1 to D9, CTW-DDR-002). Item 10 had no recommendation and stays Proposed, awaiting Amish. Item 6 carried proposed values (5 per hour, two years), which are the decision.

1. **Budget.** Parts exceed `budget_usd` ($600). Options: (a) keep $600 and define it as the kiosk only, then cut about $140 (for example a steel head in place of aluminum, a cheaper cabinet, or a smaller 10 in class display); (b) raise `budget_usd` to about $750 for the kiosk, with the TwinKit gateway costed in TwinKit; (c) raise it to about $1,050 for kiosk and gateway. Recommendation: (b), because one gateway serves many nodes and is already budgeted in TwinKit. `project.yaml` is unchanged.
2. **Display.** Color e-paper (sun-readable, low power, slow, 0 to 40 °C), monochrome e-paper (faster, no color layers), or an outdoor LCD (instant, touch possible, costly and power-hungry). Recommendation: color e-paper, plus an indoor LCD variant.
3. **Climate range.** Thermostatic heater and more shading, a wider-range panel, or indoor or sheltered siting only for the first pilot. Recommendation: sheltered or indoor siting for the pilot, then a heater study at TRL 3.
4. **Gateway location.** In the kiosk cabinet (one site, low antenna) or on a rooftop (better range, second site). Recommendation: in the cabinet for the pilot.
5. **Power.** Mains, or a solar head-only variant for sites without power. Recommendation: mains.
6. **Privacy settings.** Small-count threshold (proposed 5 per hour) and raw data retention (proposed two years).
7. **Open data license.** CC BY 4.0, CC0 or ODbL. Recommendation: CC BY 4.0.
8. **Buttons rather than a touch screen**, with the QR code handing richer use to the visitor's phone.
9. **Reference neighborhood** of 46 nodes used for sizing, and the assumed intervals for CrossSafe, FloodGauge and LoadZone.
10. **First partner city or neighborhood** for co-design and a pilot site.

### Safety concerns

- Mains voltage in the services cabinet: electrician installation, 30 mA RCBO, surge protection, earthing of all metal parts, locked door, only 12 V SELV in the head.
- LiFePO4 backup pack in the TwinKit gateway inside a sealed cabinet that can get hot in the sun.
- A roughly 55 kg post beside a walkway: footing, wind and vehicle impact, sharp edges at head height, walkway clearance, two-person lift.
- Privacy: a changed node or a new node type could try to send more than counts and levels; the schema check at the gateway and small-count suppression address this but need review.
- Over-reliance: CityTwin must not be treated as a flood or emergency warning system.

### Problems and notes

- The kit's `cutaway_parts` cuts only on a Y plane; `concept_media.py` makes its own X-plane section with the kit's renderer. Worth adding an axis option to the kit (suggestion, not done here).
- Figures on the EU regulation and Brazil's data protection law were checked on the official texts; the EU application date (June 2024) comes from the EUR-Lex record.
- The legacy `cad/src/model.py` placeholder is untouched (TRL 3 work).

### Recommended next step

Review this note and the media, then decide items 1 to 3. If approved, run `/advance-trl3` to check the data load, timing, thermal, wind and power estimates by calculation, and to agree the upload interfaces with PotholeLog, DockHub, CrossSafe, FloodGauge and LoadZone.

## Session 2026-09-26: photoreal renders

Amish asked on 2026-09-26 for photoreal renders across the portfolio, starting with the software and playbook repos (Group C). This repo has no new product model: the existing concept scene from `cad/src/concept_media.py` was rendered with Blender Cycles (`.kit/scene_export.py`, `.kit/photoreal.py`) on Amish's Mac and captioned with the project, repository and viewing direction.

- New: `media/render-hero.png`, `media/render-detail.png`. The README now leads with `media/render-hero.png`.
- Geometry, BOM, calculations and drawings are unchanged. `trl` stays 3; TRL 4 remains on hold.

## Session 2026-09-27: kit 1.5.0 and image quality

- Kit 1.5.0 synced: STANDARDS v1.5 (sections 12 to 15: product renders, storefront images and image quality, public release, authorship and signing), `.kit/cards.py`, `.kit/image_qc.py`, `.kit/release_gate.py`, issue templates, and the `/render-product` and `/release` commands. `CLAUDE.md` now matches `.kit/CLAUDE.md`.
- Every `media/render-*.png` recaptioned from its original render with the new layout: the title, concept label and repository sit in a band above the render and the view note in a band below it, each line wrapped to the image width, so no text overlaps other text or the render or runs off the image. `media/card.png` and `media/social-preview.png` regenerated with the same rules.
- `python .kit/image_qc.py` and `python .kit/release_gate.py` pass. trl stays 3.

## Session 2026-10-02: open decisions decided

Amish, 2026-10-02: "i approve your recommendations for all 555 open decisions." This approves the recommendation written for each open decision in the design decisions register (CTW-DEC-001 v0.2). trl stays 3; no build or test work was done, and the model, BOM quantities and prices, and pictures are unchanged.

### Decisions recorded

Seven decisions, all moved to Decisions made in CTW-DEC-001, dated 2026-10-02:

1. Sun shield standoff holes: option (a), drilled only in cabinets that get the shield (CTW-DDR-003, A2 accepted).
2. First partner and pilot site: a city within easy reach of Irving, Texas, with an active open-data program, as the first candidate to approach; the kiosk in a sheltered public lobby such as a library or transit center; no frost heater.
3. Antenna: post-top at 2.38 m for the pilot, with a coverage walk test at TRL 4; a rooftop gateway rather than a taller mast if nodes fall short.
4. Languages: English plus the partner city's most widely spoken other language in its own script, with a QR code and a phone or text number on the notice plate; refined in co-design.
5. Street climate (R20): kept as a post-pilot target; outdoor sites only in permanent shade with the sun shield; a panel rated above 40 °C sought at TRL 4; the heated bay only for a frost city.
6. Pull paths: daily CSV files on a fixed HTTPS address at each operator, with a published column list and a version field; the same format to be agreed in PotholeLog.
7. CrossSafe: ask for an hourly LoRaWAN summary uplink from one side of the crossing; no CrossSafe layer until it exists.

### Documents changed

- `docs/06-design-decisions.md` (CTW-DEC-001 v0.3): open decisions moved to Decisions made; the value-engineering line notes the sheltered pilot.
- `docs/decisions/0003-design-for-construction.md` (CTW-DDR-003 v0.3, status Draft): A2 accepted. The Table 1 changes (P1 to P14) were not an open decision in the register and so stayed open for Amish's review; he accepted them later on 2026-10-02 (see the next session).
- `docs/decisions/0001-trl2-review-decisions.md` (CTW-DDR-001 v0.3): O1 recorded as decided.
- `docs/decisions/0002-recommendations-accepted.md` (CTW-DDR-002 v0.2): O1, Q1 and Q2 recorded as decided.
- `docs/02-concept.md` (CTW-PRC-001 v0.7): outdoor site rule (permanent shade) and the open questions answered.
- `docs/01-problem.md` (CTW-PRB-001 v0.6): partner question answered.
- `docs/03-requirements.md` (CTW-REQ-001 v0.7): outdoor sites only in permanent shade (R20 status unchanged, not met, target after the pilot).
- `bom/bom-notes.md`: heater note (sheltered pilot).

### Follow-up actions to carry approved decisions into the design

1. Decision 1 (model and drawings): show the shield standoff holes only on the shielded variant in `cad/src/model.py`, drawing CTW-DWG-001 and the build plan pictures (section 3.3), if they are now shown on every cabinet.
2. Decision 4 (drawings and pictures): lay out the notice plate with the two languages, the QR code and the phone or text number, and update the build plan picture of the plate.
3. Decision 5 (calculations): add the permanent-shade site rule to the R20 discussion in CTW-CAL-001 when it is next run.
4. Decision 6 (docs): publish the CSV column list and version field, and agree it with PotholeLog's open item 6 (cross-repo action).
5. Decision 7 (docs): raise the hourly LoRaWAN summary uplink as a cross-repo action in CrossSafe.

### Points found in the review

- The register listed CTW-DDR-003 under Decisions made (2026-10-01) while also calling it open for Amish's review, and there was no open item to accept it. Amish accepted it later on 2026-10-02 (see the next session).
- Decision 6 is the same interface as PotholeLog's open item 6; decide both together.
- `media/render-hero.png` is missing from this copy, and the remaining renders show the concept head, hood and shield.

## Session 2026-10-02: design-for-construction changes accepted

Amish, 2026-10-02: "APPROVED: Design-for-construction changes in 10 repos (CityTwin, CoolShade, PalletPilot, Heliolite, PotholeLog, EarthPress, ReadyKit, CellCheck, CargoMule and ThermaCart)". This accepts the design-for-construction changes P1 to P14 in Table 1 of CTW-DDR-003, which were left open for his review when the open decisions were decided earlier the same day. No other item is decided by it. trl stays 3; no build or test work was done, and the model, BOM, calculations and pictures are unchanged.

### Documents changed

- `docs/decisions/0003-design-for-construction.md` (CTW-DDR-003 v0.4, status Draft): status line now "accepted" with Amish's words.
- `docs/06-design-decisions.md` (CTW-DEC-001 v0.4): Decisions made row added, dated 2026-10-02; the 2026-10-01 row no longer calls the changes open for review.
- `docs/05-build-plan.md` (CTW-BLD-001 v0.2): section 2 says CTW-DDR-003 is accepted.
- `docs/03-requirements.md` (CTW-REQ-001 v0.8): CTW-DDR-003 noted as accepted.
- `README.md` (not a controlled document): build plan paragraph says CTW-DDR-003 is accepted.
- PDFs regenerated.

### Recommended next step

No change: the follow-up actions of the previous session stand. TRL 4 remains on hold by Amish's instruction.

## Session 2026-10-02: approved follow-ups carried out

Amish approved on 2026-10-02 that every follow-up action from the open-decision sign-off be carried out. trl stays 3; nothing was built or tested.

### Follow-ups

1. Decision 1, model and drawings: done. The shield standoff holes are now cut in the cabinet only when the sun shield is fitted (`cad/src/model.py`, `shield` option); a new check confirms that the pilot cabinet has none. 245 constructability checks pass. General arrangement CTW-DWG-001 is Rev P5 and says the side holes are drilled only on outdoor sites; the build plan text for the cabinet says the sheltered pilot cabinet gets no side holes.
2. Decision 4, notice plate: done. New layout picture (`docs/05-build-plan/notice-plate.png`, Figure 19a): English, the partner city's second language in its own script, a 50 mm QR code and a phone or text number. Making sketch CTW-DWG-106 and BOM line 8 updated; the price stays $15.00 (sign-maker set-up time only, an estimate).
3. Decision 5, calculations: done. The permanent-shade rule is in the R20 discussion of CTW-CAL-001 (section F) and in the `sizing.py` R20 row; `results.csv` rerun. No number changed.
4. Decision 6, CSV column list: done here (version 1 column list and version field in CTW-PRC-001, step 5); the agreement with PotholeLog is a cross-repo action.
5. Decision 7, CrossSafe uplink: cross-repo action only.

### Requirement status changes

None. R20 stays not met (a post-pilot target for outdoor sites in permanent shade). Cost and mass are unchanged: pilot kiosk USD 778 against the USD 750 target (USD 28 over), 808 with the sun shield.

### Pictures regenerated

General arrangement CTW-DWG-001 (Rev P5), making sketch CTW-DWG-106, new notice plate layout. The model geometry of the shielded kiosk did not change, so the concept media, overview, joints and steps were not redrawn.

### Appearance model and render scene

CityTwin has no `cad/src/product_model.py` and the hero stays a scene render (the 2026-09-26 approach): the scene is built by `cad/src/concept_media.py` from `cad/src/model.py`, so it follows the model. It was exported with `.kit/scene_export.py` to `/home/claude/renders/citytwin/citytwin__hero.npz` and `.json`, with `citytwin__jobs.json`. `.kit/export_views.py` is not used because there is no product model. Photoreal images, `media/card.png` and `media/social-preview.png` are made on Amish's Mac.

### Cross-repo actions

- PotholeLog: agree the version 1 pull-path column list (CTW-PRC-001, step 5) with its open item 6; DockHub to use the same list for its hourly aggregates.
- CrossSafe: ask for an hourly LoRaWAN summary uplink from one side of the crossing; CityTwin shows no CrossSafe layer until it exists.

### Documents changed

CTW-CAL-001 v0.5, CTW-PRC-001 v0.8, CTW-BLD-001 v0.3, CTW-DDR-003 v0.5, CTW-DWG-001 Rev P5, CTW-DWG-106, `bom/bom.csv`, `bom/bom-notes.md`. PDFs re-rendered.

### Recommended next step

Make the photoreal renders on the Mac. TRL 4 remains on hold by Amish's instruction.

## 2026-10-02: photoreal renders redone on the constructable design

Rendered with Blender Cycles on Amish's Mac from the updated appearance model; captioned with `.kit/photo_caption.py`; `media/card.png` and `media/social-preview.png` regenerated with `.kit/cards.py`. Views: hero. image_qc passes. Appearance deviations are those logged above as proposed, awaiting Amish.

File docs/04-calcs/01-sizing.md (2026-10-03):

---
doc_id: CTW-CAL-001
title: CityTwin sizing calculations
project: CityTwin
doc_type: Calculation
version: "0.5"
status: Draft
date: '2026-10-02'
author: Amish Chadha
license: CERN-OHL-S-2.0
revisions:
- version: "0.1"
  date: '2026-09-25'
  author: Amish Chadha
  change: First issue for TRL 3 (radio load, storage and export, freshness and button response, legibility and shading, accessibility geometry, head and cabinet thermal with a heater study, power, wind and mass, backup, cost) with a status for every requirement
- version: "0.2"
  date: '2026-09-25'
  author: Amish Chadha
  change: Recommendations accepted by Amish (DDR-002)
- version: "0.3"
  date: '2026-10-01'
  author: Amish Chadha
  change: Constructable design (CTW-DDR-003); wind, mass and cost re-run; R16 now not met
- version: "0.4"
  date: '2026-10-01'
  author: Amish Chadha
  change: Budget treated as a value-engineering target
- version: "0.5"
  date: '2026-10-02'
  author: Amish Chadha
  change: "Permanent-shade site rule of 2026-10-02 added to the R20 discussion (section F); no number changed"
---

# CityTwin sizing calculations

On paper, CityTwin meets 16 of its 20 requirements (9 by calculation, 7 by design), has 1 at risk, misses 2 and has 1 over its value-engineering target. v0.3 re-runs the wind, mass and cost sections for the constructable design of CTW-DDR-003 (rivet nuts, front panel, display carrier, mounting plate, fixings and the parts added to the head); the parts added take the pilot kiosk to $778.00, so **R16 is over the value-engineering target by $28.00** (target $750, a hypothetical control target; see CTW-DEC-001). v0.2 applied Amish's decisions of 2026-09-25 (CTW-DDR-002): `budget_usd` of $750, R10 restated, the pilot range narrowed to 0 to 35 °C air, a ventilated sun shield on the cabinet for outdoor sites, the hood light dimmed to 0.3 W, and a larger TwinKit pack requested. **R18 is not met in the worst case**: TwinKit's backup pack rides through 2.40 h when new but only 1.63 h when aged and at 0 °C, against 2 h; a pack of at least 1.84 Ah would meet it. **R20 is not met**: in a street kiosk the panel would reach about 79 °C in low sun at 45 °C air, 45.1 °C even in shade, and needs about 13.5 W of heat at -20 °C. R1 (ingest of every node type) is at risk. R10 (LED ring in about 30 ms, layer in 19.8 s against 0.5 s and 25 s), and R12 (about 5 K of margin at 35 °C air) are met on paper. The radio and data side has ample margin: the 46-node reference neighborhood sends 5,616 uplinks a day and loses 0.61 % to collisions and downlink blanking. Several TRL 2 figures were corrected, and the v0.2 and v0.3 changes are listed in the last sections. Every number in this note is printed by `docs/04-calcs/sizing.py`; the tag in brackets, for example [A2], is the line of that script's output that carries it.

> **Safety:** These are first-principles screening estimates for a paper proof of concept. They do not replace the electrician's check of the mains installation, a structural design of the footing and anchors to the local code, or a privacy impact assessment. See CTW-PRC-001, Safety.

## Scope and method

The note checks every requirement in CTW-REQ-001 v0.5 against the design in CTW-PRC-001 v0.5, the decisions in CTW-DDR-001 to CTW-DDR-003 and the parametric model `cad/src/model.py`. The script imports the model's `PARAMS`, derived dimensions and part volumes, so the head, window, hood, cabinet, post and rail dimensions used here are the ones in the STEP files and in drawing CTW-DWG-001. It also reads `bom/bom.csv` and `budget_usd` in `project.yaml`, and writes the requirement table to `docs/04-calcs/results.csv`. Run it from the repo root with `python docs/04-calcs/sizing.py`.

The design case is the reference neighborhood of CTW-DDR-001 D9 on one TwinKit gateway in the kiosk cabinet (D4), a pilot kiosk on a sheltered site in air of 0 to 35 °C (D3, CTW-DDR-002 N5), and a street kiosk case with the cabinet sun shield for R20.

## Assumptions

*Table 1. Main assumptions. Sibling figures are from those repos' TRL 3 calculation notes.*

| Area | Assumption | Basis |
| --- | --- | --- |
| Node traffic | CurbCount 8 x 96 uplinks a day, 14 B; CrossSafe 4 x 24, 20 B; LoadZone 12 x 124, 12 B; HeatMap Node 6 x 96, 20 B; FloodGauge 4 x 96, 20 B (60 an hour in events); AirStreet 6 x 288, 20 B; NoiseMap 6 x 96, 22 B | CBC, LDZ, HMN, FLG, AST and NSM CAL-001; the CrossSafe rate is a CityTwin assumption |
| Radio | 13 B of LoRaWAN overhead, 125 kHz, CR 4/5, 8-symbol preamble; every node at SF9; pure ALOHA over 8 channels; no capture effect | TWK-CAL-001 method, conservative |
| Downlinks | LoadZone sign option on all 6 two-puck bays, 200 downlinks and 33 s of transmit a day each; the gateway cannot receive while it transmits | LDZ-CAL-001 [H5] |
| Peak hour | FloodGauge in event mode on all 4 gauges; LoadZone at 3 times its daily mean | Assumed storm and rush hour together |
| Pulled data | PotholeLog: 3 buses, 112 kB of summaries a bus-day, at most 6,000 published segment rows a day; DockHub: 24 dock-hour rows a day | PHL-PRC-001 v0.3; D11 |
| Storage | 90 B per stored value, uncompressed; values per record: CurbCount 7, CrossSafe 4, LoadZone 5, HeatMap 11, FloodGauge 6, AirStreet 10, NoiseMap 22, pulled rows 6; 56 GB free on the card, shared with TwinKit's own 4.73 GB a year | TWK-CAL-001; payload descriptions in the sibling notes |
| Timing | Network 4.7 s worst (TWK-CAL-001); layer render 30 s; kiosk redraw every 10 min; 1600 x 1200 frame at 4 bits per pixel over SPI at 10 MHz; PNG at 20 % of raw over 80 Mbit/s Ethernet; full refresh 19 s | Waveshare manual for the refresh; the rest assumed |
| Light | LED 100 lm/W; 40 % of the light reaches the screen; the 2 W strip runs dimmed to 0.3 W (CTW-DDR-002 N6) | Assumed |
| Thermal | Outside film 10 W/m²K, inside film 5 W/m²K; solar absorptance 0.5 (grey paint); sun 600 W/m² on a vertical face, 1,000 W/m² on a horizontal one; window transmits 0.85, panel absorbs 0.7; 1 mm air gap and 6 mm polycarbonate in front of the panel; TwinKit processor 29.1 K above the air around it at light load (69.1 °C at 40 °C) and throttles at 85 °C; pack charges only at 0 to 45 °C; the ventilated sun shield lets 20 % of the sun's heat reach the cabinet | TWK-CAL-001 F2; handbook ranges; to be measured |
| Power | Controller 1.0 W; button LEDs 0.1 W; e-paper 0.5 W while refreshing; hood light 0.3 W for 12 h a night (2 W at peak); TwinKit 6.41 W; 12 V supply 85 % efficient at light load; protection 0.2 W | TWK-CAL-001 D1; typical figures |
| Wind | 35 m/s gust, air 1.25 kg/m³, load factor 1.5; drag coefficient 1.3 for the head, hood and cabinet with its sun shield, 2.0 for the square post, 1.2 for the antenna; all areas loaded at once; S355 post, 355 MPa yield; M16 anchor design tension 10 kN | Screening values; the local wind code and the anchor maker's data govern |
| Mass | Steel 7,850, aluminum 2,700, polycarbonate 1,200 kg/m³ on the model volumes; bought-in items by estimate (display 1.2 kg, TwinKit 1.2 kg) | Model; estimates |

## A. Radio load and capacity (R1, R2)

- **Traffic.** The reference neighborhood of 46 LoRaWAN nodes sends 5,616 uplinks a day (TRL 2: 4,896), mainly because LoadZone's TRL 3 note sets 124 uplinks a day per puck, not 64 [A1, A2]. At SF9 the uplinks take 1,309 s a day, 1.52 % of one channel, or 0.189 % of each of 8 channels [A2].
- **Loss.** Collisions lose 0.38 % of uplinks. With the LoadZone sign option on all six bays, 1,200 downlinks take 198 s of gateway transmit a day, during which the gateway hears nothing: another 0.23 %, for 0.61 % in all [A3]. In a storm hour with every FloodGauge in event mode and LoadZone at three times its mean, the gateway sees 582 uplinks an hour and loses 0.94 % plus the same blanking [A4].
- **Capacity (R2).** 10,000 records a day of 20 B at SF9 lose 0.71 %; one gateway takes up to 14,075 a day before loss reaches 1 %, consistent with TwinKit's 1.02 % at 14,400 [A5]. **R2 is met on paper.**
- **Pulled sources (R1).** PotholeLog uploads its daily summaries (3 buses x 112 kB) to the fleet operator's server, not to CityTwin, and DockHub syncs its logs over LTE-M to its own back end. Under D11 the gateway fetches the published PotholeLog segment files (at most 6,000 rows a day) and DockHub's 24 dock-hour rows a day by outbound HTTPS, so it still accepts no inbound connection [A6]. CrossSafe's radio runs LoRa point to point between the two sides of a crossing and has no LoRaWAN uplink defined; the 24 summaries a day assumed here depend on CrossSafe adding one. **R1 is at risk**: met on paper for six LoRaWAN types, with the PotholeLog and DockHub paths proposed but not agreed and the CrossSafe uplink undefined.

## B. Storage and open export (R2, R6)

- **Store.** 87,936 values a day take 2.89 GB a year uncompressed. Two years of raw records (D6) are 5.78 GB and ten years of hourly aggregates 15.14 GB, 20.9 GB in all [B1]. With TwinKit's own two-year case the card holds 30.4 GB of 56 GB free [B2].
- **Export (R6).** Each day the export carries 1,104 node-hour rows, up to 6,000 road segment rows and 24 dock rows: 7,128 rows, 0.86 MB as CSV and 2.85 MB as GeoJSON, or 1.35 GB a year on the public host [B3]. PotholeLog segments dominate; the TRL 2 figure of 0.2 MB a day left them out. **R6 is met by design**; the sizes confirm that one-way pushes of this volume are trivial.

## C. Freshness and button response (R8, R10)

- **Data age (R8).** For a 15 min node, the newest value can be 15 min old when the next uplink arrives, and the kiosk may then wait up to 10 min for its next redraw. With 4.7 s of network time, 30 s to render the layer, 0.79 s to move the image and 19 s to refresh, the worst age on the kiosk is 25.9 min; if one uplink is lost (0.38 % chance) it is 40.9 min. The web map shows data at most 15.6 min old [C1]. **R8 is met on paper**, with a margin of about 4 min.
- **Button (R10).** A press starts a 960 kB frame transfer (0.79 s) and a full refresh (19 s): 19.8 s against the restated 25 s (CTW-DDR-002 N2; the TRL 2 target was 5 s). The controller lights the pressed button's LED ring after a 10 ms poll and 20 ms debounce, about 30 ms against 0.5 s, and keeps it lit until the new image is drawn [C2]. **R10 is met on paper** for the street kiosk. The indoor LCD variant keeps the 5 s target and is not modeled at TRL 3.

## D. Legibility, night light and shading (R9)

- **Text.** The panel has 150 pixels per inch, so 7 mm capitals are 41 px tall and subtend 16.0 arcmin at 1.5 m: 3.2 times the 5 arcmin of a 20/20 letter and 1.6 times the 10 arcmin of 20/40 [D1].
- **Night.** At its full 2 W the hood light gives about 1,459 lx on the 0.0548 m² screen; 200 lx needs only 0.27 W, so under CTW-DDR-002 N6 it runs dimmed to 0.3 W, which gives about 219 lx [D2].
- **Sun.** The hood reaches 140 mm beyond the head. With the sun facing the screen, its shadow covers 13 % of the window at 30°, 31 % at 45° and 63 % at 60° elevation [D3]. The hood shades the screen at midday but not in low morning or evening sun, which matters for R20 below.
- **R9 is met on paper**: reflective e-paper reads in sun by design, and the text size and night light have margin.

## E. Accessibility geometry (R11)

The buttons sit at 1,120 mm, inside the 380 to 1,220 mm reach range. The head's leading edge runs from 1,040 to 1,722 mm, inside the 685 to 2,030 mm zone (27 to 80 in) where objects on posts may overhang no more than 305 mm (12 in) ([U.S. Access Board, protruding objects](https://www.access-board.gov/ada/guides/chapter-3-protruding-objects/), checked 2026-09-25). The head overhangs the post by 180 mm sideways and the hood by 200 mm sideways and 190 mm forward. The cabinet with its sun shield projects 186.5 mm behind the post, and its bottom, at 300 mm, is below 685 mm and within cane reach [E1]. **R11 is met on paper** for the kiosk; the WCAG 2.1 AA web page is not verifiable at TRL 3. The screen center at 1.46 m is high for a seated reader; the web page and the QR code carry the same content.

## F. Thermal: head, heater study and cabinet (R12, R20)

- **Pilot head (R12).** The head holds 1.12 W of electronics and loses heat from 0.786 m², a rise of 0.14 K in shade. At 35 °C air, the top of the pilot range under CTW-DDR-002 N5, the panel sits at 35.1 °C, 4.9 K under its 40 °C rating; at 40 °C air it would be 40.1 °C, and the limit for air is 39.9 °C [F1].
- **Street head in sun (R20).** With 600 W/m² of low sun on the face, the head air rises 9.2 K, and the panel, which absorbs 19.6 W through the window, sits 33.6 K above the air outside: about 79 °C at 45 °C air [F2]. Only orientation or shading of the face can fix this, which is why a shaded screen orientation is a site rule (N4); the hood does not shade low sun. Even in shade the panel is at 45.1 °C in 45 °C air. Site rule decided by Amish on 2026-10-02 (CTW-DEC-001): outdoor sites only in permanent shade, with the sun shield; this is the 45.1 °C and 52.2 °C case above, not the 79 °C sun case, and the panel is still over its 40 °C rating at 45 °C air, so a panel rated above 40 °C is sought at TRL 4.
- **Heater study (R20).** Holding the panel at 0 °C in -20 °C air takes 156 W if the whole head is heated, but only 13.5 W if the panel sits in a bay lined with 20 mm of foam and the heater warms only that bay [F3]. Under N4 the heater is fitted only where the partner city has frost.
- **Cabinet.** The sealed cabinet holds 7.96 W (TwinKit 6.41 W, supply loss 1.35 W, protection 0.2 W). Its air rises 4.4 K in shade and 18.7 K in sun, when it absorbs 78 W. Behind the ventilated sun shield (item 19, N4) it absorbs about 16 W and rises 7.2 K, so the pack stays under its 45 °C charge limit in full sun up to 37.8 °C air [F4]. In the pilot case (35 °C shaded) the cabinet air is 39.4 °C, the TwinKit processor 68.5 °C against 85 °C, and the pack 5.6 K below its charge limit; at 40 °C in shade the margin is only 0.6 K. Outdoors at 35 °C in sun with the shield the cabinet air is 42.2 °C (2.8 K margin). At 45 °C the pack is over the limit in every case: 49.4 °C shaded, 52.2 °C in sun with the shield and 63.7 °C without it, when the processor reaches 92.8 °C, above its throttle point [F5]. At -20 °C air the cabinet is at -15.6 °C, too cold to charge the pack [F6].
- **Status.** **R12 is met on paper** with about 5 K of margin for the panel and the pack. **R20 is not met**; it stays a post-pilot target for outdoor sites in permanent shade only (decided 2026-10-02).

## G. Power (R14, R15)

- **Average (R15).** The head draws 1.27 W of 12 V DC (controller 1.0 W, hood light 0.15 W averaged over 12 h a night at 0.3 W, button LEDs 0.1 W, e-paper 0.016 W). With TwinKit's 6.41 W and an 85 % supply, the kiosk takes 9.2 W from the mains: 0.222 kWh a day, 81 kWh a year [G1]. **R15 is met on paper.** A street kiosk with the panel heater running at -20 °C would take 25.1 W while heating [G2], above 15 W; how long it runs depends on the site's climate.
- **Supply (R14).** The 12 V peak is 26.7 W (TwinKit 20.6 W, controller boot 2.5 W, e-paper 1.5 W, hood 2 W, LEDs 0.1 W), or 40.2 W with the heater, within the 60 W supply. The mains current is 40 mA at 230 V [G3], far below the 6 A RCBO rating. **R14 is met by design** and the supply size is confirmed.

## H. Wind, structure and mass (R13)

- **Loads.** At 35 m/s the dynamic pressure is 766 Pa. The head and hood take 342 N at 1.38 m, the cabinet with its sun shield 200 N at 0.54 m, the post 268 N at 0.88 m and the antenna 11 N at 2.08 m [H1]: 821 N and a base moment of 839 N·m, or 1,258 N·m with the 1.5 load factor [H2].
- **Post and weld.** The 100 x 100 x 4 mm section (47,268 mm³) is stressed to 26.6 MPa, a factor of 13.3 on yield [H2]. A 4 mm fillet weld all round the post base sees 33.4 MPa [H3].
- **Anchors and plate.** Each anchor on the tension side carries 1.94 kN, a factor of 5.1 on the assumed 10 kN [H5]. The 12 mm base plate sees 40 MPa [H6]. The head moves 0.63 mm under the unfactored gust [H7].
- **Mass.** The kiosk weighs 63.5 kg with the sun shield (post 21.4, base 15.3, cabinet with mounting plate and rails 12.8, head tray and front panel 4.2, sun shield with its back panel and standoffs 1.94 kg) [H4], about 61.6 kg without it. The TRL 2 figure was about 55 kg; v0.2 had 60.1 kg before the mounting plate, front panel and fixings were modeled.
- **R13 is met on paper.** The TRL 2 figure of 12 MPa left out the post's own drag and the load factor. Vehicle impact is not covered; the footing and anchors are site design.

## I. Outage behavior (R18)

TwinKit's backup runs the gateway for 2.40 h with a new pack and 1.63 h with an aged pack at 0 °C, against the 2 h of R18. The head is not on the backup; the bistable e-paper keeps its last image and time stamp [I1]. Scaling TwinKit's 1.5 Ah pack by 2 h over 1.63 h, a pack of at least 1.84 Ah would meet R18 in the worst case; under CTW-DDR-002 N3 TwinKit is asked for it [I1]. **R18 is not met in the worst case** until TwinKit changes its pack. A cold cabinet in winter (section F) would shorten the runtime further.

## J. Cost (R16, R17)

All 21 BOM lines are priced. The pilot kiosk (items 1 to 12, 14, 15, 20 and 21) costs $778.00; the TwinKit gateway $290.00 from TwinKit's TRL 3 BOM; together $1,068.00. The outdoor sun shield (item 19) adds $30.00, for $808.00 [J1]. Against the value-engineering target (`budget_usd`, $750 under CTW-DDR-002 N1, a hypothetical control target), the estimated pilot kiosk cost is $28.00 over and the outdoor kiosk $58.00 over [J2]. **R16 is over the value-engineering target by $28.00**: the display carrier (item 20, $8.00), the fixings (item 21, $22.00) and the head's converter, LED driver and terminal block (item 6, up $13.00), less $4.00 moved out of item 15, are needed to build the kiosk (CTW-DDR-003). Savings worth trying are in the Value engineering section of CTW-DEC-001. **R17**, redefined by D1 as a reported figure with the gateway costed in TwinKit, is met on paper.
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

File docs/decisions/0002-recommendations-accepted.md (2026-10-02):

---
doc_id: CTW-DDR-002
title: CityTwin recommendations accepted
project: CityTwin
doc_type: Design decision record
version: "0.2"
status: Draft
date: '2026-10-02'
author: Amish Chadha
license: CERN-OHL-S-2.0
revisions:
- version: "0.1"
  date: '2026-09-25'
  author: Amish Chadha
  change: Record the recommendations accepted by Amish on 2026-09-25, what changed in the repo and the items still open
- version: "0.2"
  date: '2026-10-02'
  author: Amish Chadha
  change: O1, Q1 and Q2 decided by Amish on 2026-10-02 as recommended
---

# 0002: Recommendations accepted

- **Date:** 2026-09-25
- **Status:** accepted. Every item below that carried a recommendation is decided by Amish, 2026-09-25: go with recommendation. Items with no recommendation stayed "Proposed, awaiting Amish"; O1, Q1 and Q2 were decided on 2026-10-02 as recommended in CTW-DEC-001 (Amish, 2026-10-02: "i approve your recommendations for all 555 open decisions.").
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

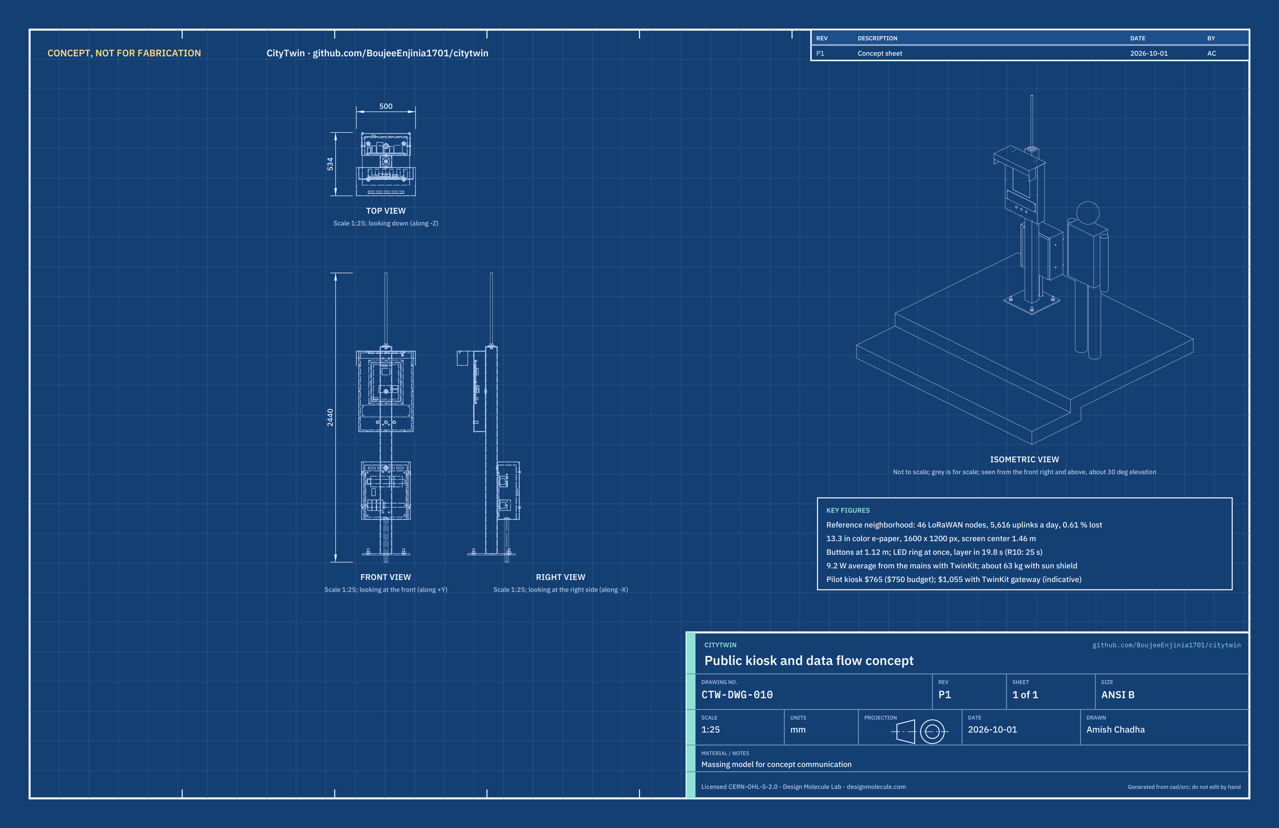
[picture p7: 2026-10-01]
media/concept-blueprint.png

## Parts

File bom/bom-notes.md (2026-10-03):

# BOM notes

Costs are indicative estimates for a single prototype, in USD, updated for TRL 3 (CTW-CAL-001 section J). Every line is priced and carries a supplier or supplier type. Only the e-paper display price was checked against the maker's own listing (September 2026); the TwinKit gateway price comes from TwinKit's TRL 3 BOM. Suppliers are not yet selected.

- **Pilot kiosk parts** (items 1 to 12, 14, 15, 20 and 21): $778.00. The value-engineering target (`budget_usd`) is $750, a hypothetical control target and not a limit (set when Amish accepted the recommendations on 2026-09-25, CTW-DDR-002 N1), and under CTW-DDR-001 D1 it covers the kiosk only. The parts added on 2026-10-01 to make the kiosk buildable (CTW-DDR-003: display carrier, fixings, the head's converter, LED driver and terminal block) take the estimated cost $28.00 over the target; savings worth trying are in CTW-DEC-001.
- **Cabinet sun shield** (item 19, outdoor sites only, CTW-DDR-002 N4): $30.00. The outdoor kiosk is $808.00, $58.00 over the value-engineering target; it is reported, not counted under R16, because the pilot is on a sheltered site.
- **TwinKit gateway** (item 13): $290.00, costed in the TwinKit repo. A city that already runs TwinKit only needs the kiosk.
- **Kiosk with gateway**: $1,068.00, reported under R17.
- Screws, rivet nuts, tapes and gaskets are now their own line (21); line 15 keeps the conduit, cables, grommets and earth bonds.
- The notice plate (item 8) now carries two languages, a 50 mm QR code and a phone or text number (CTW-DEC-001, 2026-10-02). Its price stays $15.00: the extra printed content adds sign-maker set-up time, not material, and the figure is an estimate, not a quote.
- Items 16 to 18 are software and documents with no parts cost. Hosting for the public open data files is not included.
- The 60 W supply (item 12) covers the 26.7 W peak, and 40.2 W with the street heater studied in CTW-CAL-001; the panel heater is not in the BOM, because it is fitted only where the partner city has frost (CTW-DDR-002 N4); the pilot is in a sheltered public lobby (decided 2026-10-02), so it is not fitted.
- Not included: concrete footing, anchor design, mains connection by an electrician, permits and installation labor.

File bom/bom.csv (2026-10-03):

item | qty | spec | supplier | unit_cost_usd | make_buy | notes
1 Base plate and anchors | 1 | 400 x 400 x 12 mm steel plate welded to the post (4 mm fillet all round): four 18 mm anchor holes on a 300 mm square, a 25 mm vent and drain hole under the post, a 40 mm conduit hole 130 mm behind the post center; four M16 anchors with nuts and 34 mm washers into a concrete footing or existing slab | Local steel fabricator; anchors from a fixings distributor | 35.00 | make | Indicative price; footing and anchor design resistance are site work and not included (CTW-CAL-001 section H); post and plate are one welded fabrication, hot-dip galvanized (CTW-DDR-003)
2 Post | 1 | 100 x 100 x 4 mm square hollow section, 1.75 m, with a 6 mm welded cap (20 mm coax hole, four M5 tapped holes); front wall: four 11 mm holes for M8 rivet nuts (head) and a 25 mm cable hole at 1.38 m; back wall: four 11 mm holes for M8 rivet nuts (cabinet) and a 25 mm cable hole at 0.735 m; hot-dip galvanized and powder coated | Local steel fabricator | 60.00 | make | Indicative price; drill before galvanizing, set rivet nuts after coating (CTW-DDR-003); bending stress in CTW-CAL-001 section H
3 Display head enclosure | 1 | Folded 2 mm aluminum tray 460 x 98 x 680 mm with a 15 mm return flange round the front, vent slots underneath, four 9 mm holes in the back for the post screws, a 25 mm cable hole; removable 2 mm aluminum front panel 460 x 680 mm with a 240 x 320 mm window opening, three 19.2 mm button holes, eight M4 x 25 clinch studs, 12 tamper-resistant M4 screws into rivet nuts in the flange; EPDM gasket strip; IP54 target | Local sheet metal shop | 85.00 | make | Indicative price; tray and front panel from the same sheet metal shop (CTW-DDR-003)
4 Front window | 1 | 6 mm UV-stabilized polycarbonate, anti-glare, 256 x 336 mm, bonded inside the front panel lapping the 240 x 320 mm opening by 8 mm with 1 mm acrylic glazing tape (line 21) | Plastics supplier | 25.00 | buy | Indicative price
5 E-paper display | 1 | 13.3 in E Ink Spectra 6 color panel, 1600 x 1200 px, 270.4 x 202.8 mm active area, with driver HAT; full refresh about 19 s; rated 0 to 40 degC | Waveshare (13.3inch e-Paper HAT+ (E)) | 255.00 | buy | List price $249.99 to $259.99 on the maker's site (checked 2026-09-25 at TRL 2); temperature range limits the pilot to sheltered or indoor sites (CTW-DDR-001 D3)
6 Kiosk controller | 1 | Raspberry Pi Zero 2 W class board, 32 GB industrial microSD, USB Ethernet adapter, real-time clock; 12 V to 5 V 3 A buck converter; 4-channel low-side LED driver module (three button rings and the hood light); pluggable 6-way terminal block with a 2 A fuse; all on the display carrier | Raspberry Pi approved reseller or electronics distributor | 55.00 | buy | Indicative price; pulls the rendered layer image from the gateway over a wired link; converter, LED driver and terminal block added for construction (CTW-DDR-003)
7 Push buttons | 3 | 19 mm stainless vandal-resistant momentary buttons with LED ring, 24 mm bezel, IP65, in 19.2 mm holes with their own nuts | Electronics distributor | 8.00 | buy | Indicative price; LED ring confirms a press while the screen redraws
8 Data notice plate | 1 | Printed or engraved 2 mm aluminum plate, 400 x 100 mm, four 4.5 mm corner holes: three zones of printed content: English, the partner city's second language in its own script, and a 50 mm QR code to the sensor register over a phone or text number (what is measured, who is responsible, retention); four M4 tamper-resistant screws with nyloc nuts inside the front panel | Local sign maker | 15.00 | make | Indicative price; icons in the style of the open DTPR standard
9 Sun and rain hood with light | 1 | Folded 1.5 mm aluminum hood, 500 mm wide, reaching 240 mm from the post (140 mm beyond the head), 60 mm front lip and 120 mm side cheeks, four M5 tamper-resistant screws into rivet nuts in the head top; 12 V warm white LED strip, about 2 W, on a 20 x 20 x 1.5 mm aluminum angle riveted under the roof behind the lip, dusk sensor | Local sheet metal shop plus electronics distributor | 35.00 | make | Indicative price; lights the e-paper at night
10 Services cabinet | 1 | Lockable steel cabinet, 360 x 160 x 460 mm, IP55, door on the back of the post, with its 340 x 390 mm mounting plate on 10 mm standoffs carrying two 320 mm TS35 DIN rails, earth stud; drilled: four 9 mm holes and a 25 mm cable hole in the wall against the post, a 32.5 mm gland hole in the floor, four 6.5 mm standoff holes in the sides (outdoor sites) | Electrical wholesaler | 55.00 | buy | Indicative price; the upper rail carries the TwinKit gateway exactly as laid out in TWK-DWG-001 (294 mm used); fixed to the post with four M8 screws into rivet nuts (CTW-DDR-003)
11 Mains protection | 1 | RCBO 6 A 30 mA (2 modules) and Type 2 surge protective device (2 modules) on the DIN rail | Electrical wholesaler | 45.00 | buy | Indicative price; installed or checked by a qualified electrician
12 12 V DIN power supply | 1 | 230 V or 120 V AC in, 12 V 60 W out, 3 modules, certified (SELV output), with output terminals | Electrical wholesaler (Mean Well HDR-60-12 class) | 25.00 | buy | Indicative price; peak load 26.7 W (39.8 W with the street heater studied in CTW-CAL-001)
13 TwinKit gateway | 1 | TwinKit DIN rail gateway per TWK-DWG-001: terminals and 3.15 A T fuse, 9-module enclosure, DC-DC converter, UPS module with 12.8 V 1.5 Ah LiFePO4 pack, LoRaWAN concentrator; coax lead to item 14 in place of the whip | TwinKit project (bom/bom.csv in TwinKit) | 290.00 | make | Not in kiosk cost; costed in the TwinKit repo (CTW-DDR-001 D1); $290.00 from the TwinKit TRL 3 BOM
14 LoRaWAN antenna and bracket | 1 | Antenna, N-type bulkhead and coax from the TwinKit BOM; 60 x 60 x 6 mm aluminum bracket plate with a 16.5 mm bulkhead hole, four M5 screws into the post cap; tip at 2.38 m | TwinKit project; local fabricator | 8.00 | make | Bracket only; antenna cost is in item 13
15 Conduit and cabling | 1 | 32 mm mains feed conduit from the footing through the base plate into a gland in the cabinet floor; 12 V cable, Ethernet cable and coax up the post; four rubber grommets for the 25 mm cable holes; earth bonds | Electrical wholesaler | 26.00 | buy | Indicative price; screws, rivet nuts and other fixings moved to line 21 (CTW-DDR-003)
16 Map dashboard | 1 | Open-source web map on the gateway: one layer per node type, time slider, as-of timestamp, accessible web version | CityTwin project | 0.00 | make | Software (MIT); no parts cost; no exploded-view callout
17 Open data export | 1 | Hourly CSV and GeoJSON files with a documented schema under CC BY 4.0, pushed one way to a public host; OGC SensorThings API proposed | CityTwin project | 0.00 | make | Software (MIT); no parts cost; no exploded-view callout
18 Data governance templates | 1 | Sensor register entry, data sharing policy, privacy impact assessment outline, community agreement | CityTwin project | 0.00 | make | Documents; no parts cost; no exploded-view callout
19 Cabinet sun shield (outdoor sites) | 1 | Folded 1.5 mm aluminum, 413 x 186 x 486 mm: top and two sides with 15 mm flanges at the back, on four 25 mm M6 aluminum standoffs bolted through the cabinet sides with sealing washers; separate back panel over the cabinet door with four vent slots high up, held by four M5 knurled thumb screws into rivet nuts in the flanges; 25 mm air gap, open at the bottom; powder coated light grey | Local sheet metal shop | 30.00 | make | Indicative price; fitted on outdoor sites only (CTW-DDR-002); fixing changed for construction (CTW-DDR-003); not in the sheltered pilot kiosk cost under R16
20 Display carrier | 1 | 2 mm aluminum plate 290 x 370 mm, eight 4.5 mm stud holes, 70 x 8 mm ribbon slot; holds the e-paper panel against the window and carries the driver board and controller on M2.5 standoffs | Local sheet metal shop | 8.00 | make | Indicative price; new part for construction (CTW-DDR-003)
21 Fixings, tapes and gaskets | 1 | Stainless: 8 M8 steel flush rivet nuts, 8 M8 x 20 button-head screws with 30 mm penny washers, 16 M4 and 4 M5 aluminum rivet nuts, 12 M4 tamper-resistant screws (front panel), 4 M4 tamper-resistant screws and nyloc nuts (notice plate), 4 M5 tamper-resistant screws (hood), 4 M5 screws (antenna bracket), 8 M4 x 15 spacers and nuts, 8 M2.5 standoffs; 1 mm acrylic glazing tape 8 mm wide, 1 mm foam gasket tape | Fasteners distributor; electrical wholesaler | 22.00 | buy | Indicative price; new line for construction (CTW-DDR-003)

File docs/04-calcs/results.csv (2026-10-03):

id | requirement | value | target | status
R1 | Ingest every node type | 6 LoRaWAN types on paper; PotholeLog and DockHub by outbound pull (D11), not agreed; CrossSafe has no LoRaWAN uplink | All 9 types | At risk
R2 | Capacity on one gateway | 46 nodes, 5,616/day, loss 0.38 %; 10,000/day gives 0.71 % | 50 nodes, 10,000/day | Met on paper
R3 | Counts and levels only | Per-type schema at the decoder | Reject out-of-schema fields | Met by design
R4 | Small-count suppression | Threshold 5 per hour (D6) | Fewer than 5 published as such | Met by design
R5 | No movement traces | Segment per day; dock per hour | No tracks, no card IDs | Met by design
R6 | Open data export | 7,128 rows/day, 0.86 MB CSV | Hourly CSV and GeoJSON, CC BY 4.0 | Met by design
R7 | One map | Layer per type, health, as-of time | As stated | Met by design
R8 | Data freshness | 25.9 min worst on the kiosk | 30 min | Met on paper (thin margin)
R9 | Readable day and night | 7 mm = 41 px, 16.0 arcmin; 219 lx at night (light dimmed to 0.3 W) | Sun and night at 1.5 m | Met on paper
R10 | Button response (restated) | LED ring 30 ms; layer 19.8 s | Acknowledged within 0.5 s; layer within 25 s | Met on paper
R11 | Accessible kiosk | Buttons 1120 mm; overhang 200 mm | 380 to 1,220 mm; 305 mm; WCAG page | Met on paper (web page not verifiable at TRL 3)
R12 | Pilot climate (redefined) | Panel 35.1 C and pack 39.4 C at 35 C air | Sheltered site, air 0 to 35 C | Met on paper
R13 | Wind | 26.6 MPa with factor 1.5; anchors 1.94 kN | 35 m/s gust x 1.5, no yield | Met on paper
R14 | Electrical safety | Mains only in the cabinet; 12 V SELV; peak 26.7 W of 60 W | As stated | Met by design
R15 | Running power | 9.2 W | 15 W | Met on paper
R16 | Pilot kiosk parts cost | $778.00 (outdoor with shield $808.00) | $750 (budget_usd) | Not met ($28.00 over)
R17 | Cost with gateway (redefined, D1) | $1,068.00 | Reported; gateway costed in TwinKit | Met on paper (reported)
R18 | Honest in an outage | 2.40 h new, 1.63 h worst; 1.84 Ah pack needed | 2 h ride-through | Not met (worst case)
R19 | Secure by default | Outbound push and pull only | No inbound connections | Met by design
R20 | Street climate (target after the pilot) | Panel 79 C in sun, 45.1 C shaded at 45 C; pack 52.2 C behind the shield; heater 13.5 W at -20 C | -20 to +45 C air; outdoor sites only in permanent shade (decided 2026-10-02) | Not met

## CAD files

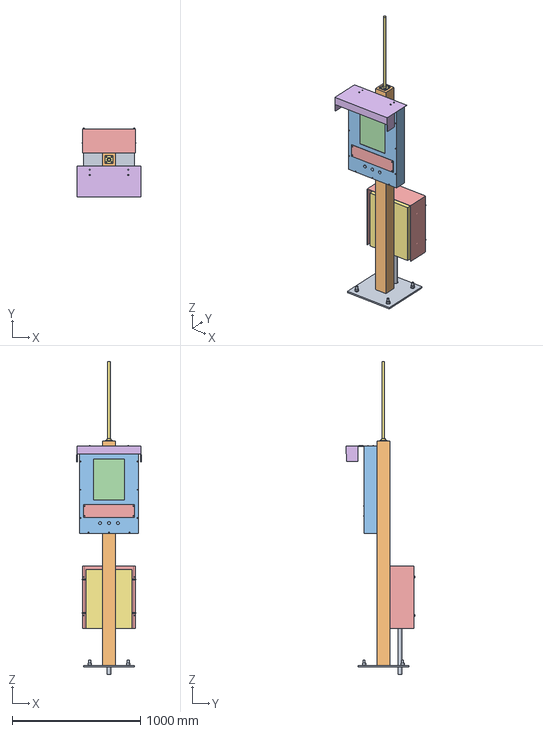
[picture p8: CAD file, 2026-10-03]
cad/step/citytwin-kiosk-assembly.step
500.0 x 534.5 x 2440.0 mm

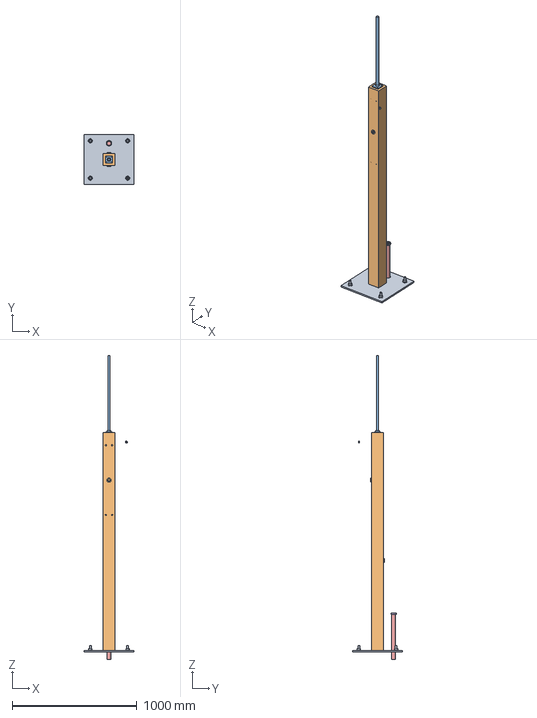
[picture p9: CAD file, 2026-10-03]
cad/step/post-and-base.step
400.0 x 400.0 x 2440.0 mm

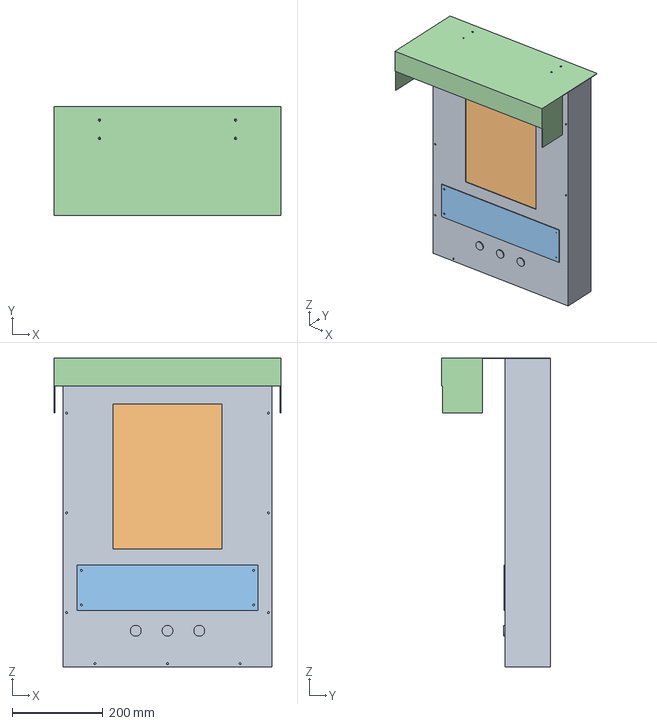
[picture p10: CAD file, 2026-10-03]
cad/step/kiosk-head.step
500.0 x 240.0 x 681.5 mm

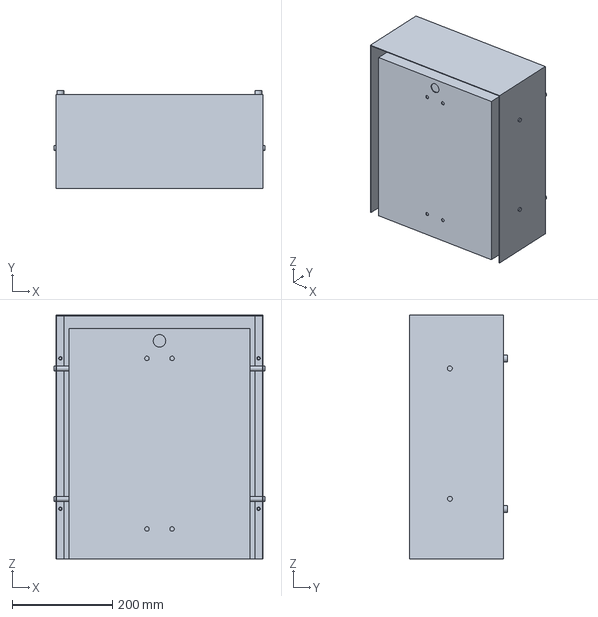
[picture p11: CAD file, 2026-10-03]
cad/step/services-cabinet.step
420.0 x 194.5 x 486.5 mm

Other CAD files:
cad/stl/citytwin-kiosk-assembly.stl
cad/stl/kiosk-head.stl
cad/stl/post-and-base.stl
cad/stl/services-cabinet.stl

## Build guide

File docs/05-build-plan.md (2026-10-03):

---
doc_id: CTW-BLD-001
title: CityTwin prototype build plan
project: CityTwin
doc_type: Build plan
version: "0.3"
status: Draft
date: '2026-10-02'
author: Amish Chadha
license: CERN-OHL-S-2.0
revisions:
  - version: "0.1"
    date: '2026-10-01'
    author: Amish Chadha
    change: First build plan, with pictures by component and step; design made constructable (CTW-DDR-003)
  - version: "0.2"
    date: '2026-10-02'
    author: Amish Chadha
    change: "Section 2: the changes recorded in CTW-DDR-003 accepted by Amish on 2026-10-02"
  - version: "0.3"
    date: '2026-10-02'
    author: Amish Chadha
    change: "Notice plate layout picture (two languages, QR code, phone or text number); side holes only in shielded cabinets; document references brought up to date"
---

# CityTwin prototype build plan

**Plan, not yet built.** How to build the first proof-of-concept prototype of the CityTwin kiosk, component by component. Building and testing to it is TRL 4 work. Decisions still to be made are kept in the design decisions register ([docs/06-design-decisions.md](06-design-decisions.md)), not here.

## 1. What you are building

Figure 1. Every component, pulled apart and numbered in build order

*Figure 1. Every component pulled apart and numbered in build order; 20 and 21, the sun shield and its back panel, are fitted on outdoor sites only.*

The prototype is the physical part of CityTwin: a public kiosk about 2.4 m tall to the antenna tip. A 100 mm square steel post, welded to a base plate, stands on four anchors. On its street side it carries a folded aluminum display head with a 13.3 in color e-paper screen behind a polycarbonate window, three push buttons, a data notice plate and a hood with a night light. On its back it carries a locked steel cabinet holding the mains protection, a 12 V supply and the TwinKit gateway that runs the CityTwin software, with an antenna on the post top. Figure 1 shows the 21 components in the order you make or fit them. Ten are made: the base plate and post (one welded, galvanized part from a steel fabricator), the head tray, front panel, display carrier, hood, notice plate and antenna bracket (from a sheet metal shop and a sign maker), and the sun shield and its back panel for outdoor sites; the bought cabinet is drilled. Everything else is bought and fitted: the window, e-paper panel, controller and small modules, buttons, DIN rail devices, the TwinKit gateway, conduit, cables and fixings. The work in your own workshop is drilling, setting rivet nuts, bonding the window, fitting boards and low-voltage wiring; the mains wiring is done by a qualified electrician. The parts for the sheltered pilot kiosk cost about $778 from the bill of materials.

> **Safety:** The cabinet carries mains voltage (230 V or 120 V). Only a qualified electrician installs or checks the mains feed, the RCBO, the surge protector and the earthing, to local electrical code. The TwinKit gateway holds a lithium iron phosphate backup pack: keep its fuse out until safety stop S4. The kiosk weighs about 64 kg; lift the post with two people or a hoist. Cut steel and aluminum edges are sharp: deburr everything, and round every corner at head height.

## 2. What changed to make it buildable

The concept showed what the kiosk does; many of its parts touched with nothing holding them, and the head was a sealed box. Each change below keeps what the kiosk does, and all of them are recorded in decision record CTW-DDR-003, accepted by Amish on 2026-10-02.

*Table 1. Changes from the concept.*

| Component | The concept had | The buildable design has | Why |
| --- | --- | --- | --- |
| Post | A closed tube touched by the head and cabinet, with no fixing | Eight M8 flush rivet nuts set in the post walls; the head and cabinet are each held by four M8 screws from inside (Figures 7 and 10) | A nut can be set in a closed tube from outside |
| Base plate and post | Anchors fused to the plate; a sealed tube | 18 mm anchor holes, washers and nuts; a 25 mm vent and drain hole under the post; a 40 mm conduit hole (Figure 3) | A closed tube cannot be safely galvanized; the mains feed needs a way in |
| Display head | A sealed 2 mm box with no way in | A folded tray with a return flange, closed by a removable front panel on twelve tamper-resistant screws (Figure 17) | It can be made by folding, and opened for service |
| Window and screen | Floating in the head | Window bonded inside the front panel with glazing tape; the screen pressed onto it by a new display carrier on eight studs (Figure 21) | The glass panel is held evenly and lifts out with the front panel |
| Head electronics | A 12 V feed only | A 5 V converter, an LED driver and a pluggable, fused terminal block on the carrier (Figure 22) | The controller needs 5 V; the button rings and hood light need switching; the front panel must unplug |
| Buttons and notice plate | 24 mm holes; no fixing for the plate | 19.2 mm holes with each button's own nut; four tamper-resistant screws for the plate (Figure 18) | How these parts really mount |
| Hood | A solid 14 mm block with no fixing | Folded 1.5 mm sheet on four screws into rivet nuts in the head top; the LED strip on an angle behind the lip (Figure 12) | A real folded part with a real fixing |
| Cabinet | Rails drawn on the wall; a cable slot that met a solid wall | Rails on the cabinet's mounting plate; 25 mm grommeted cable holes through the post and cabinet, and through the post and head; a conduit gland in the floor (Figure 8) | Cables stay inside the post; mains stays in the cabinet |
| Antenna bracket | A solid block | A 6 mm plate screwed to the post cap, with the antenna's bulkhead through it (Figure 14) | A plate a small shop can make |
| Sun shield | Hook tabs that hooked onto nothing; a one-piece "lift-off" back | Four 25 mm standoffs on the cabinet sides; a separate back panel on four thumb screws (Figure 24) | A fixing that holds the 25 mm air gap and comes off by hand |

## 3. Making the components

Make and check each component before the assembly step that needs it. Sizes are in millimeters. Heights are from the sidewalk unless a step says "from the bottom edge". "Front" is the street side, where the screen faces; "left" and "right" are as seen standing in front of the kiosk. Workshop tolerance is 0.5 mm on holes and 1 mm on sheet sizes unless a step says otherwise; drawings do not carry tolerances before TRL 4.

### 3.1 Base plate

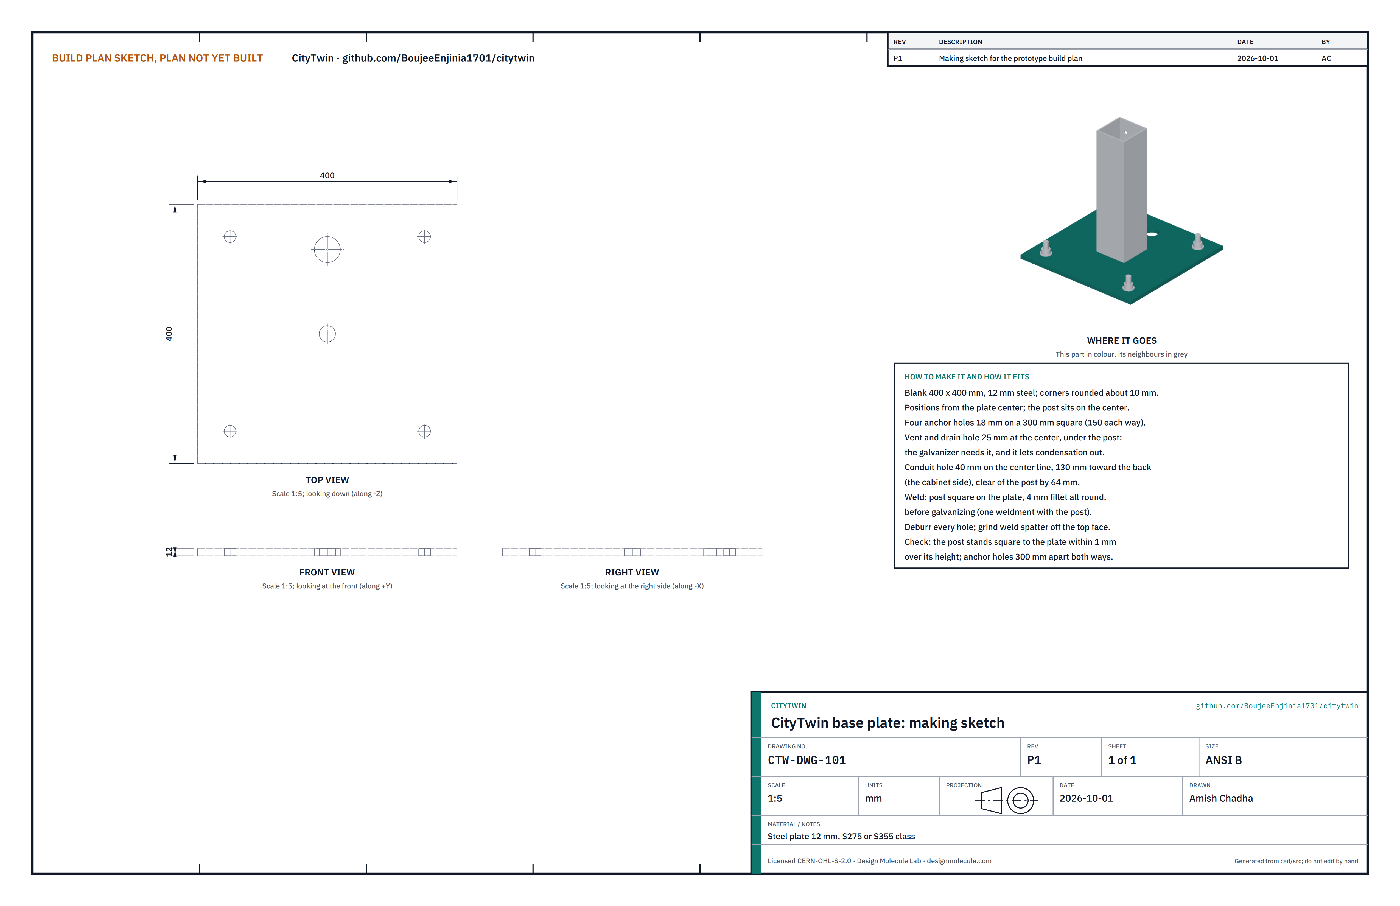
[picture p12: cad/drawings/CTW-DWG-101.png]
Figure 2. Making sketch of the base plate


*Figure 2. Base plate making sketch (CTW-DWG-101).*

**What it is and what it is made from.** The square steel plate the post is welded to; it bolts to the footing. Steel plate 12 mm thick, S275 or S355 class, 400 x 400 mm. The base plate and the post are made as one welded part by a steel fabricator.

**How to make it.**

1. Cut the blank to 400 x 400 mm and round the corners to about 10 mm.
2. Mark the center and two center lines. The side toward the cabinet is the back.
3. Drill four 18 mm anchor holes on a 300 mm square: 150 mm each way from the center.
4. Drill a 25 mm hole at the center. It sits under the post: the galvanizer needs it to vent the tube, and it lets condensation drain.
5. Drill a 40 mm hole on the center line, 130 mm behind the center, for the mains conduit.
6. Deburr every hole.

**How it fits the parts next to it.**

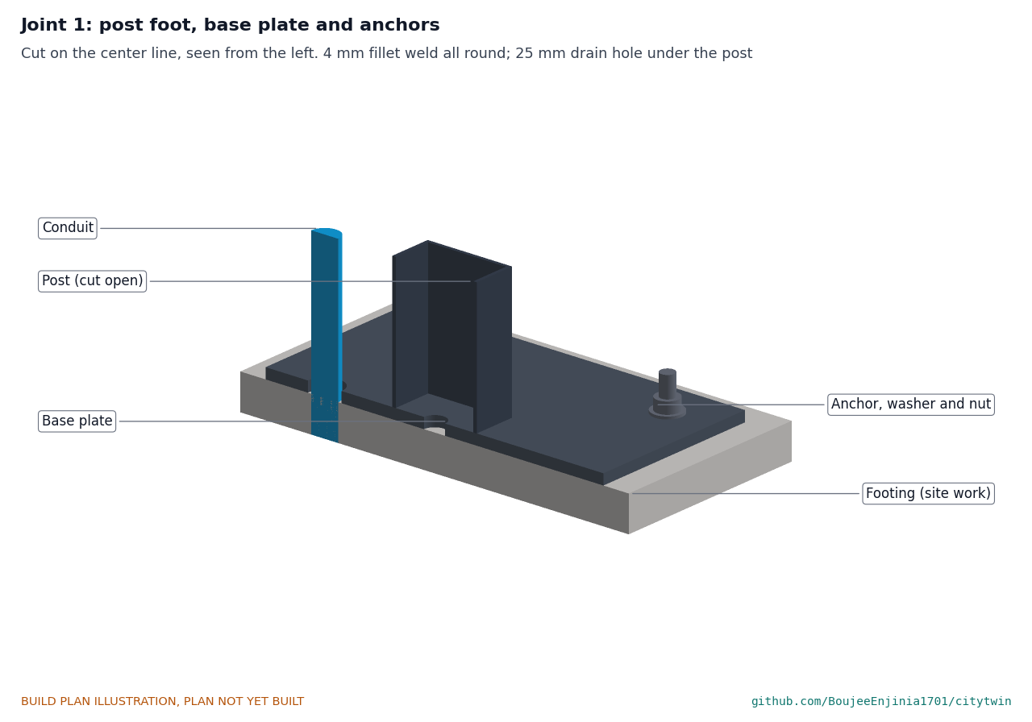
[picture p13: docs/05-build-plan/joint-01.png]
Figure 3. Joint 1: post foot, base plate and anchors


*Figure 3. The post stands on the plate's center with a 4 mm fillet weld all round; the drain hole is inside the post; the conduit rises through its own hole behind the post.*

The post is welded square on the plate before galvanizing (section 3.2). The plate sits on the footing on steel shims or a grout bed. Each anchor passes up through its 18 mm hole and takes a 34 mm washer and a nut on top of the plate.

**Check before moving on.** The anchor holes are 300 mm apart both ways, measured center to center, and the post stands square to the plate within 1 mm over its height.

### 3.2 Post

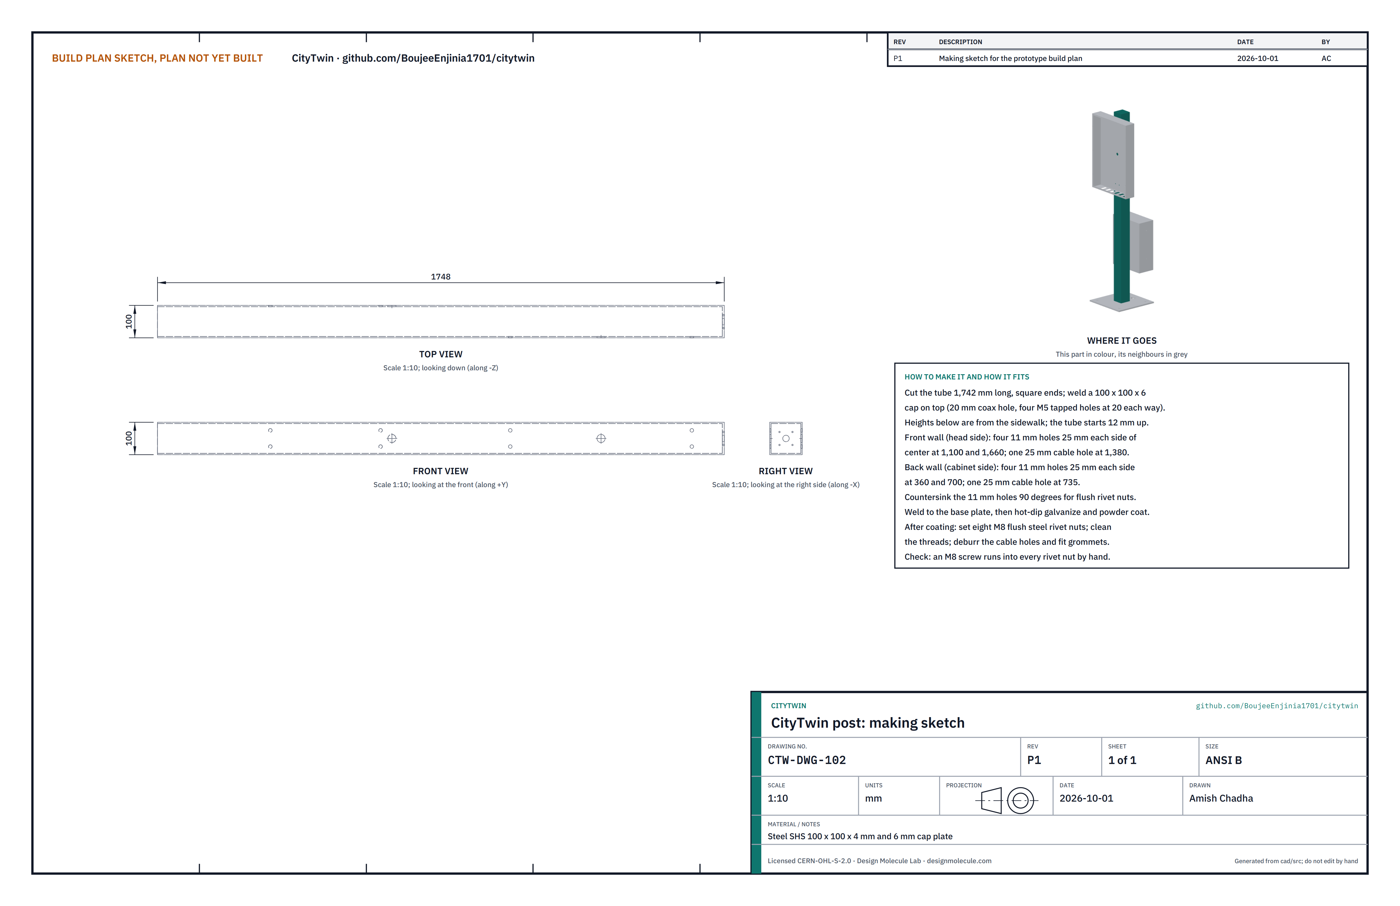
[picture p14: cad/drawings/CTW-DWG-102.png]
Figure 4. Making sketch of the post


*Figure 4. Post making sketch (CTW-DWG-102), drawn lying down.*

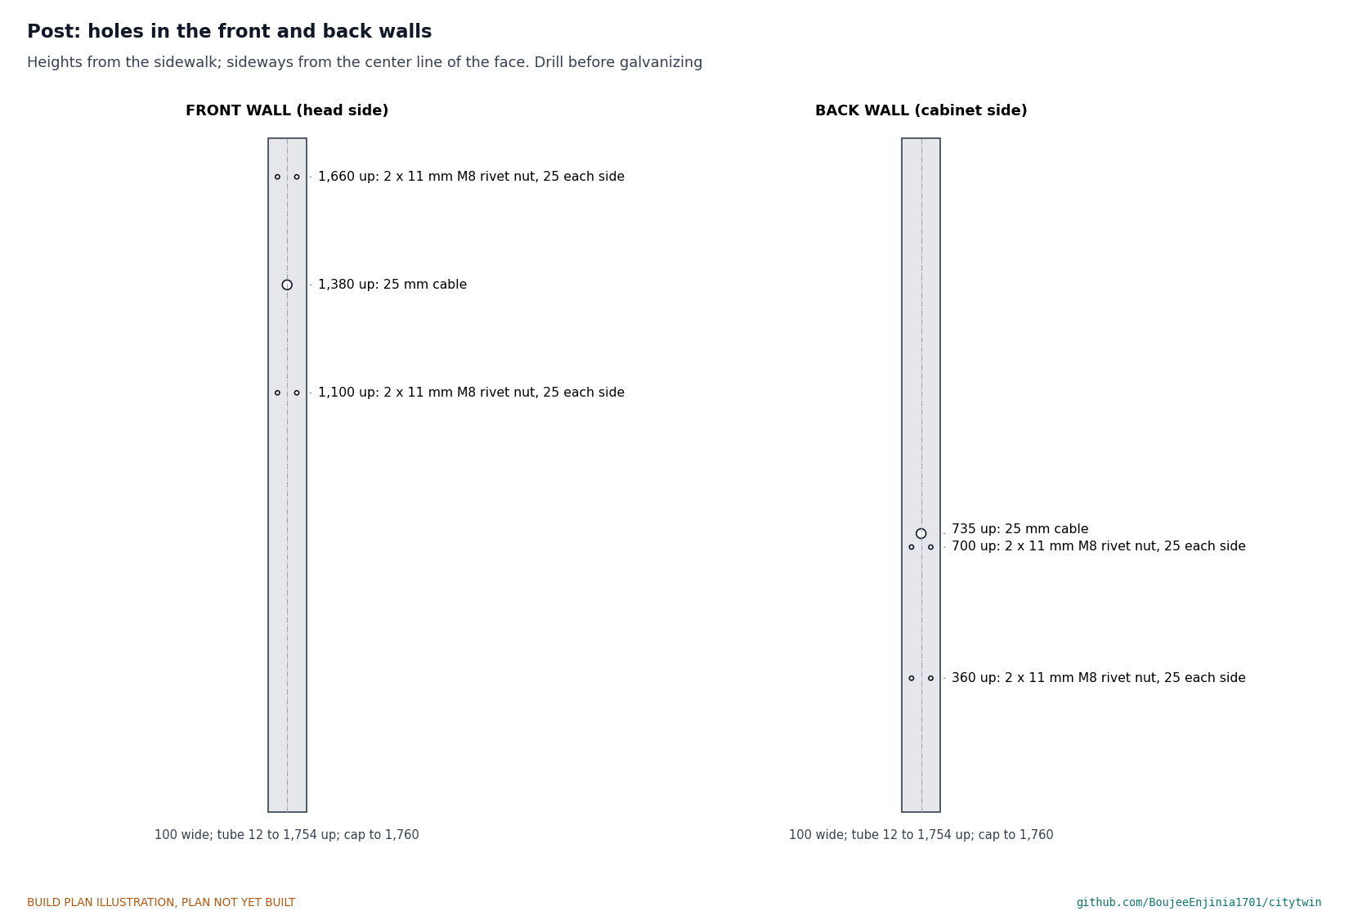
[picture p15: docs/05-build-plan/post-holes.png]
Figure 5. Holes in the post's front and back walls


*Figure 5. Every hole in the front wall (head side) and back wall (cabinet side), with heights from the sidewalk.*

**What it is and what it is made from.** The 1.75 m column that carries the head, the hood, the cabinet and the antenna, and carries the low-voltage cables inside it. Square hollow steel section 100 x 100 x 4 mm, with a 6 mm steel cap plate on top.

**How to make it.**

1. Cut the tube 1,742 mm long with square ends. With the 12 mm base plate under it and the 6 mm cap on it, the top is 1,760 mm up.
2. Cap plate: 100 x 100 x 6 mm, with a 20 mm hole at the center for the antenna cable and four M5 tapped holes 20 mm each way from the center for the antenna bracket.
3. Front wall (street side), as Figure 5: four 11 mm holes 25 mm each side of the center line, at 1,100 and 1,660 mm up; one 25 mm cable hole on the center line at 1,380 mm up.
4. Back wall (cabinet side): four 11 mm holes 25 mm each side of the center line, at 360 and 700 mm up; one 25 mm cable hole on the center line at 735 mm up.
5. Countersink the eight 11 mm holes 90 degrees so the flush rivet nuts sit level with the wall.
6. Weld the cap on top and weld the tube to the base plate (section 3.1).
7. Send the welded part for hot-dip galvanizing, then powder coating.
8. After coating, set eight M8 flush steel rivet nuts in the 11 mm holes with a rivet nut tool, clean the threads and deburr the two cable holes.

**How it fits the parts next to it.** The head tray's back sits flat on the front wall, held by four M8 screws into the front rivet nuts (Figure 10). The cabinet's back wall sits flat on the back wall, held by four M8 screws into the back rivet nuts (Figure 7). The two cable holes line up with matching holes in the cabinet and the head tray, each with a rubber grommet. The antenna bracket sits on the cap (Figure 14).

**Check before moving on.** An M8 screw runs into every rivet nut by hand; each rivet nut is flush with the wall and does not spin.

### 3.3 Services cabinet, drilled

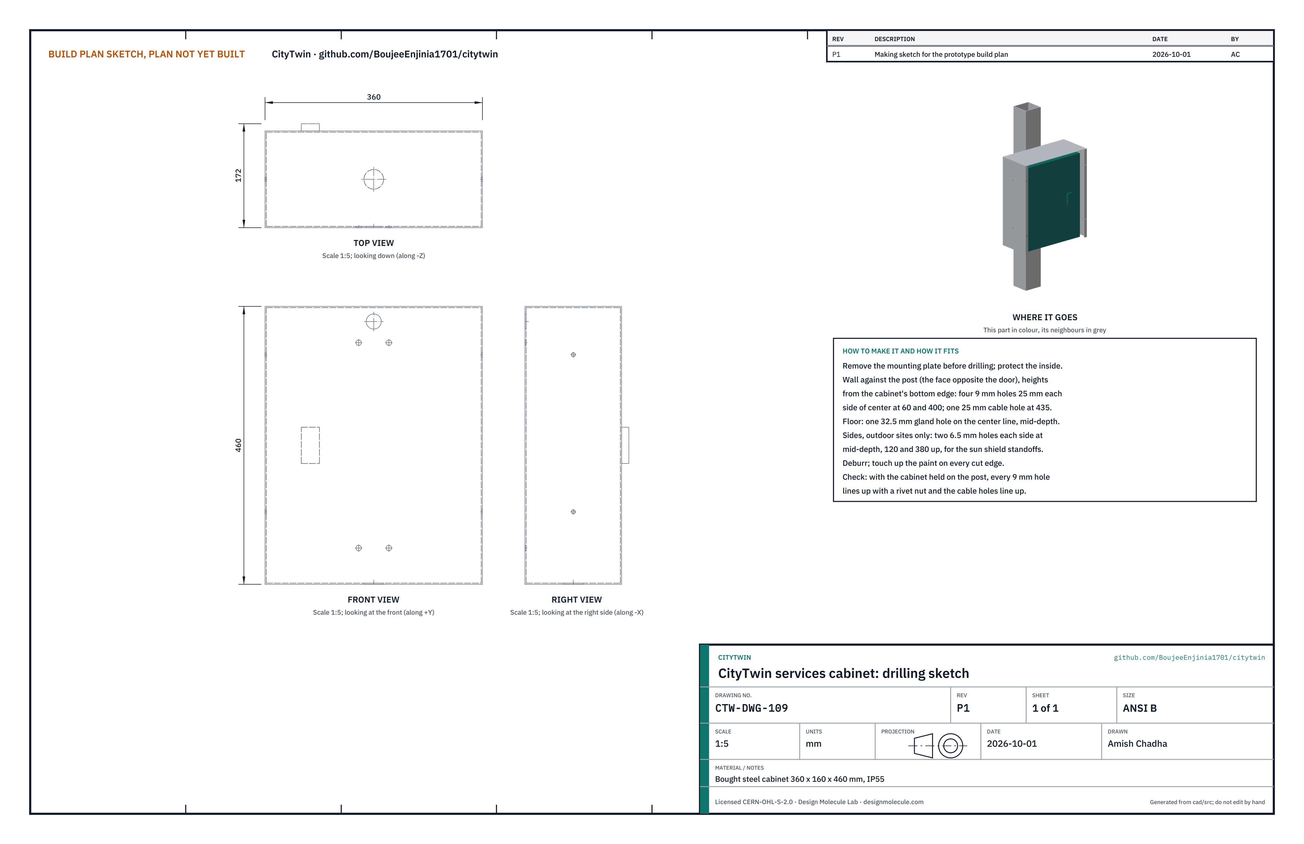
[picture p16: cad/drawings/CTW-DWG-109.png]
Figure 6. Drilling sketch of the services cabinet


*Figure 6. Services cabinet drilling sketch (CTW-DWG-109).*

**What it is and what it is made from.** A bought, lockable steel electrical cabinet, 360 wide, 160 deep and 460 mm tall, rated IP55, with its door on the face away from the post and a removable mounting plate inside. It holds every mains part and the TwinKit gateway.

**How to make it.**

1. Take out the mounting plate and protect the inside from swarf.
2. On the wall that goes against the post, with heights from the cabinet's bottom edge: four 9 mm holes 25 mm each side of the center line at 60 and 400 mm up, and a 25 mm cable hole on the center line at 435 mm up, above the mounting plate.
3. In the floor: a 32.5 mm hole on the center line at mid-depth for the conduit gland.
4. Outdoor sites only: two 6.5 mm holes in each side wall at mid-depth, 120 and 380 mm up, for the sun shield standoffs. The pilot cabinet, on a sheltered site, gets no side holes.
5. Deburr and touch up the paint on every cut edge.

**How it fits the parts next to it.**

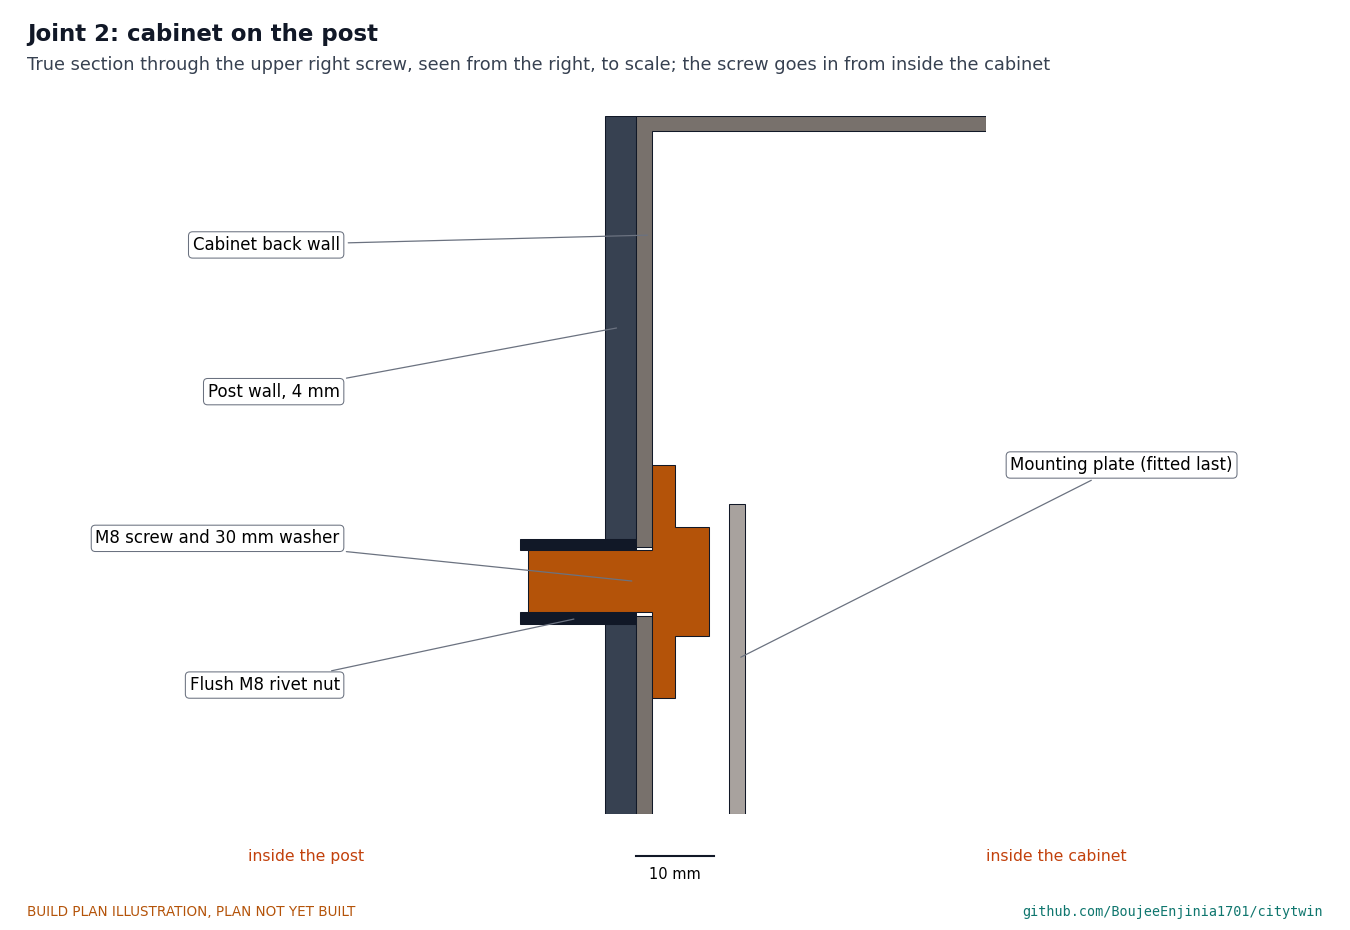
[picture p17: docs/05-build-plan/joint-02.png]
Figure 7. Joint 2: cabinet on the post


*Figure 7. The cabinet's back wall sits flat on the post; an M8 screw with a 30 mm washer goes in from inside the cabinet into the flush rivet nut. The mounting plate goes in after the screws.*

The cabinet is 300 mm above the sidewalk, centered on the post. Four M8 button-head screws with 30 mm washers go in from inside the cabinet. The mounting plate then goes back on its four studs, 10 mm off the back wall, clear of the screw heads. The cable hole lines up with the post's 25 mm hole at 735 mm, with a grommet each side.

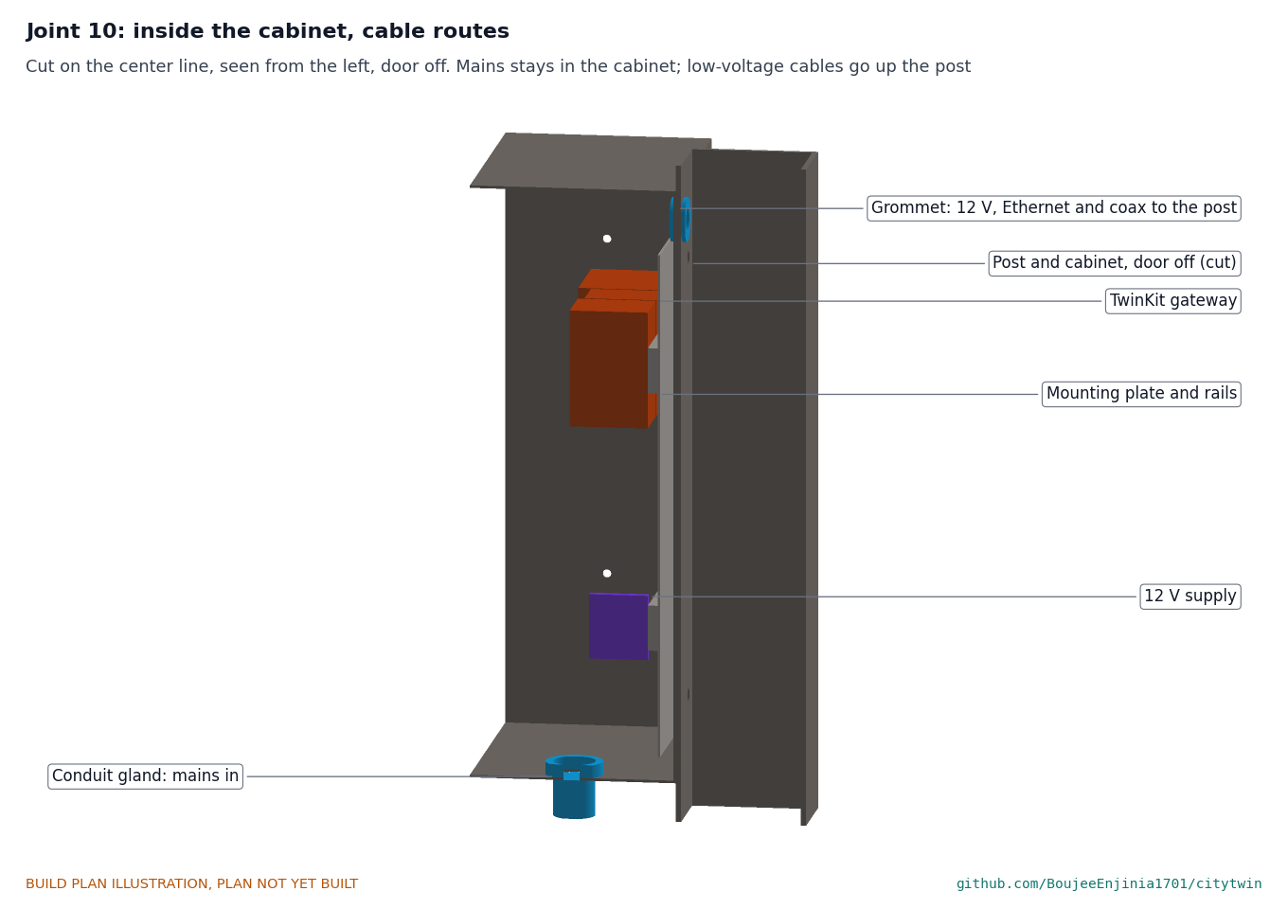
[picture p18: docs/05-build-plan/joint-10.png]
Figure 8. Joint 10: inside the cabinet, cable routes


*Figure 8. The mains feed enters through the conduit gland in the floor and stays in the cabinet; the 12 V cable, Ethernet cable and antenna cable leave through the grommet into the post.*

**Check before moving on.** Held on the post, every 9 mm hole lines up with a rivet nut and the cable holes line up.

### 3.4 Head tray

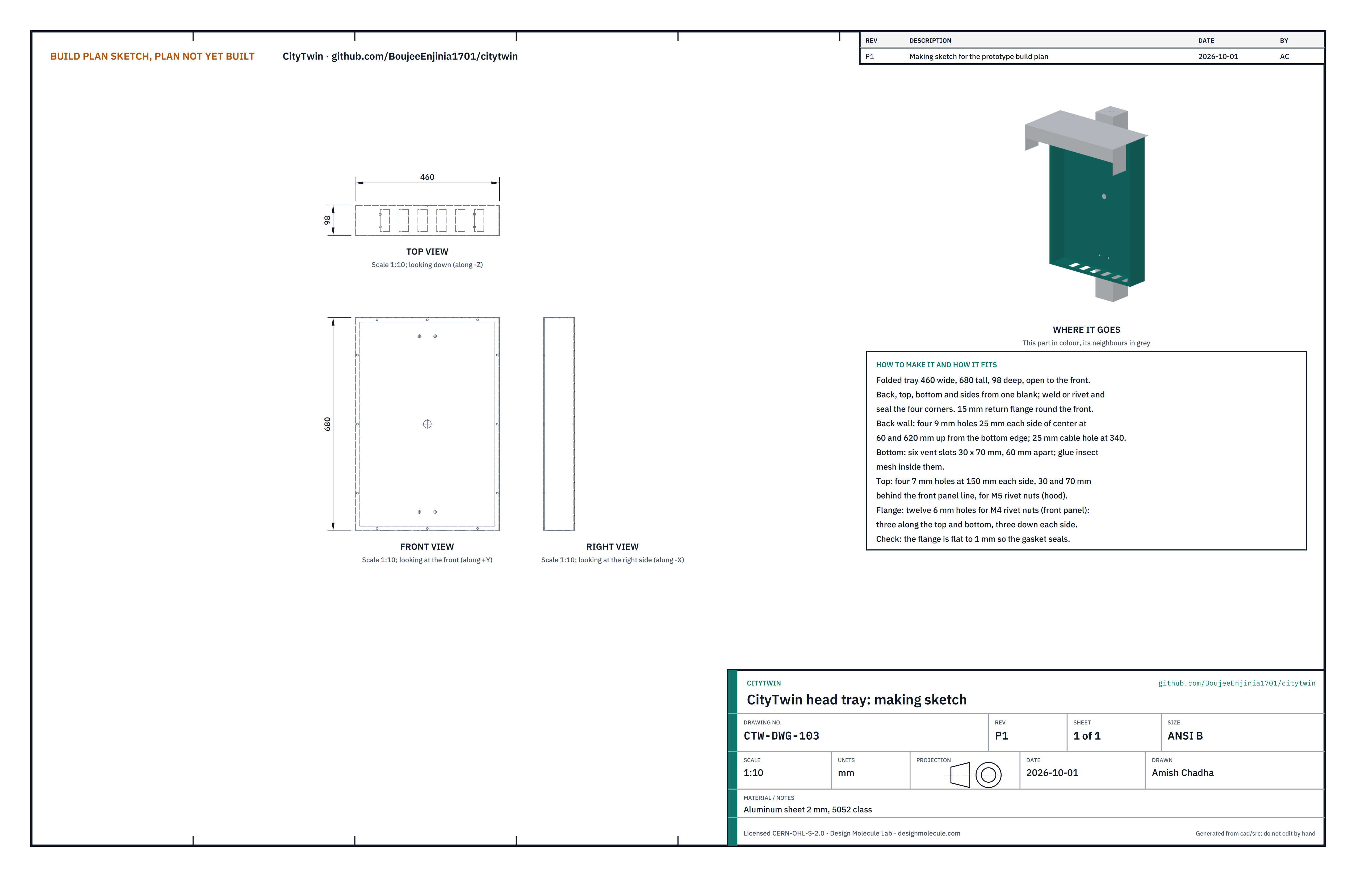
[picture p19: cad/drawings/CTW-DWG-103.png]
Figure 9. Making sketch of the head tray


*Figure 9. Head tray making sketch (CTW-DWG-103).*

**What it is and what it is made from.** The body of the display head: a box 460 wide, 680 tall and 98 mm deep, open at the front, which the front panel closes. Aluminum sheet 2 mm, 5052 class, folded by a sheet metal shop.

**How to make it.**

1. Fold the back, top, bottom and two sides from one blank, and weld or rivet and seal the four corners.
2. Fold a 15 mm return flange inward all round the open front.
3. Back wall, with heights from the bottom edge: four 9 mm holes 25 mm each side of the center line at 60 and 620 mm up; a 25 mm cable hole on the center line at 340 mm up.
4. Bottom: six vent slots 30 x 70 mm, 60 mm apart; glue stainless insect mesh inside them.
5. Top: four 7 mm holes 150 mm each side of the center line, 30 and 70 mm behind the front panel line; set M5 aluminum rivet nuts in them for the hood.
6. Flange: twelve 6 mm holes, three along the top, three along the bottom and three down each side, matching the front panel (Figure 16); set M4 aluminum rivet nuts in them.
7. Powder coat.

**How it fits the parts next to it.**

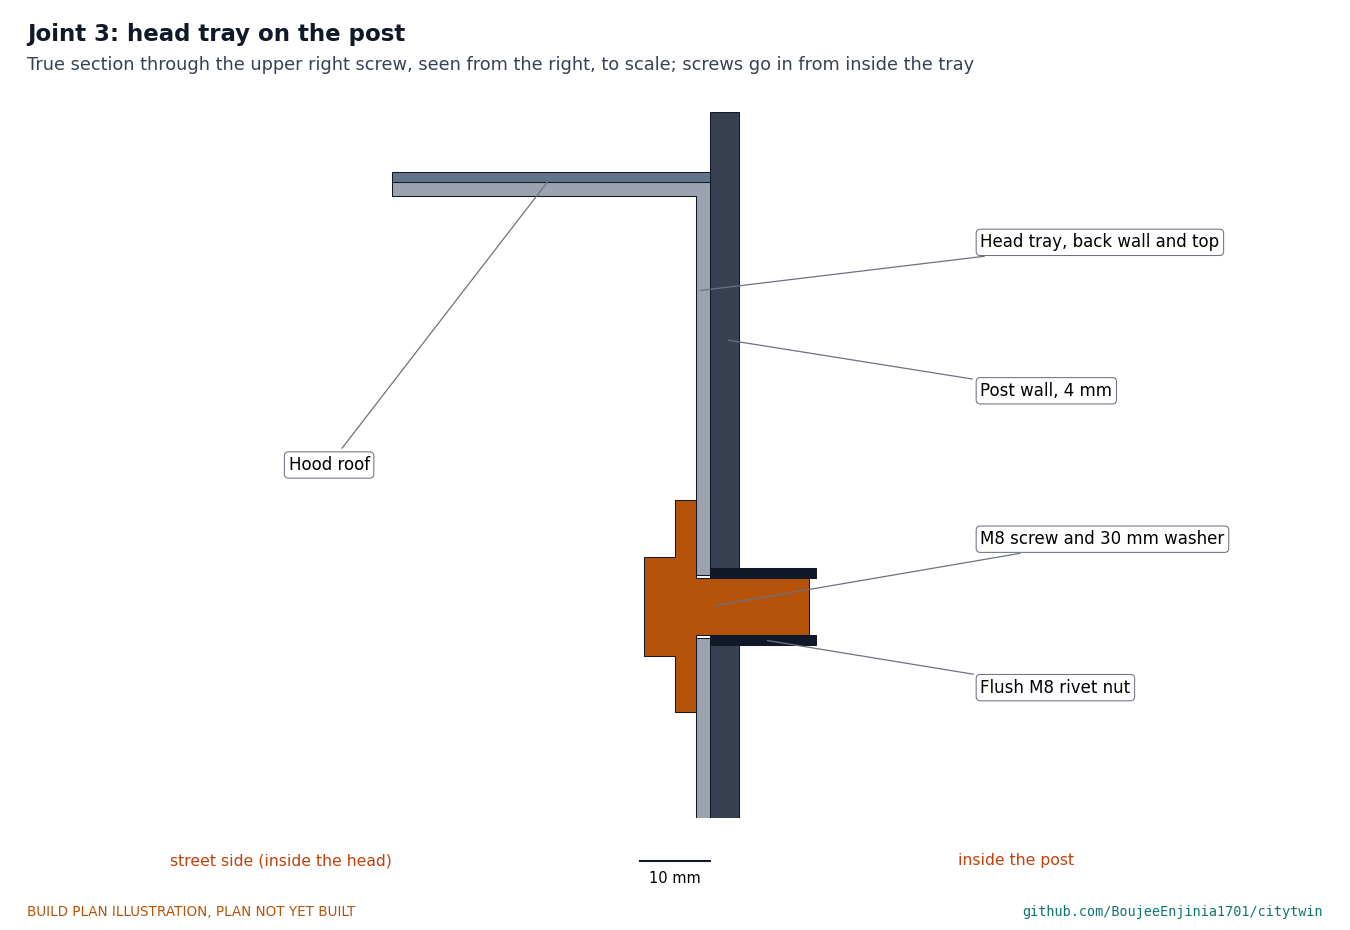
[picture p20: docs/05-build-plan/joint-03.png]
Figure 10. Joint 3: head tray on the post


*Figure 10. The tray's back wall sits flat on the post's front wall; an M8 screw with a 30 mm washer goes in from inside the tray into the flush rivet nut.*

The tray's bottom edge is 1,040 mm up and its top 1,720 mm up, centered on the post. The four screws go in from inside, before the front panel is fitted. The 30 mm washers spread the load on the 2 mm wall.

**Check before moving on.** The flange is flat within 1 mm so the gasket seals, and all twelve rivet nuts take an M4 screw by hand.

### 3.5 Hood

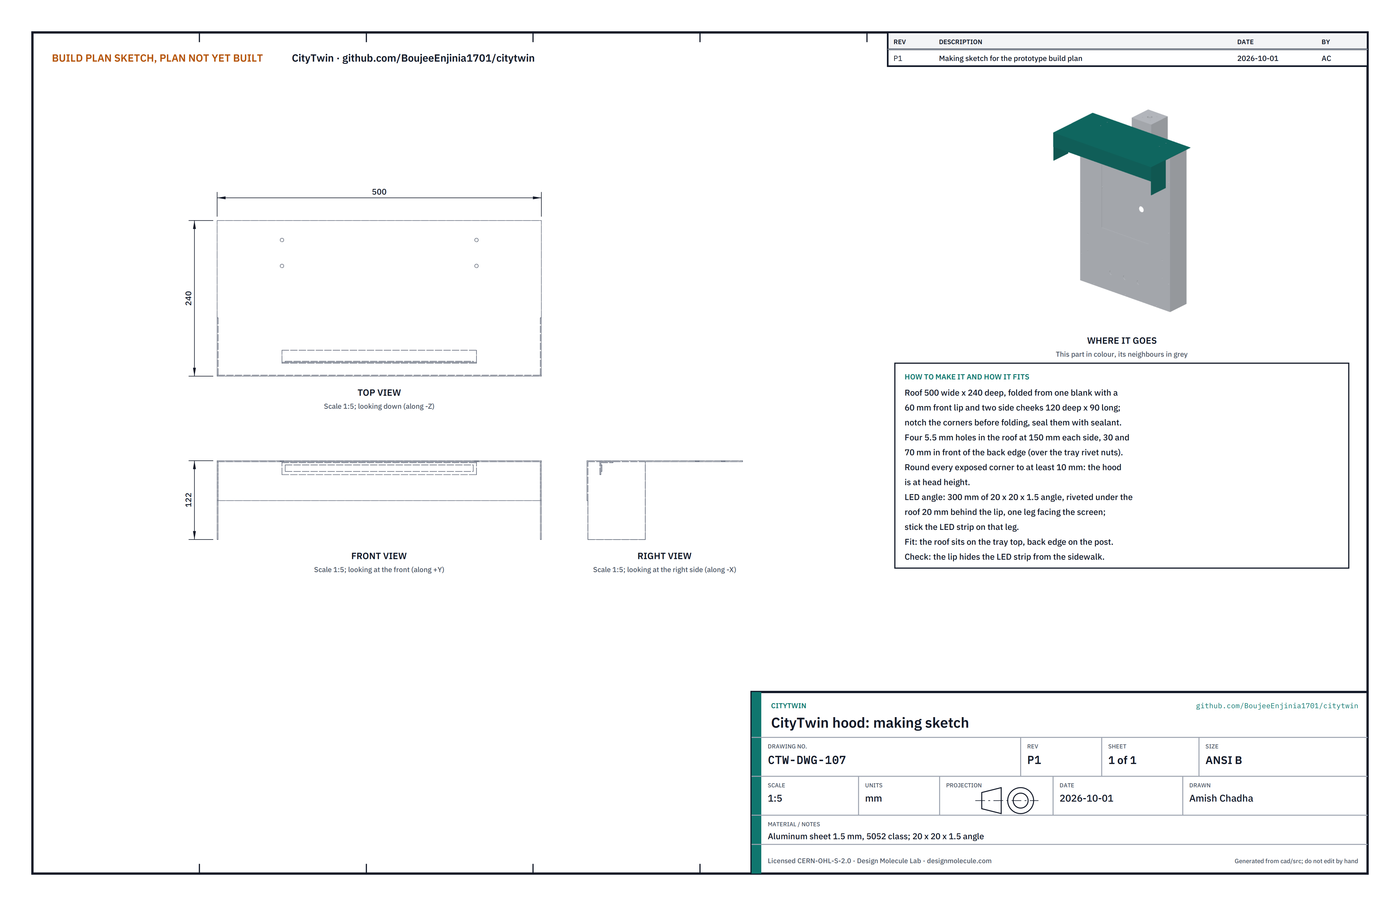
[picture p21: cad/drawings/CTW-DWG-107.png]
Figure 11. Making sketch of the hood


*Figure 11. Hood making sketch (CTW-DWG-107).*

**What it is and what it is made from.** The roof that shades the screen by day and hides the night light. Aluminum sheet 1.5 mm, 5052 class, and a 300 mm length of 20 x 20 x 1.5 mm aluminum angle.

**How to make it.**

1. Cut one blank and fold a roof 500 wide and 240 mm deep, a 60 mm lip down along the front edge, and two side cheeks 120 mm deep and 90 mm long. Notch the corners before folding and seal them after.
2. Drill four 5.5 mm holes in the roof, 150 mm each side of the center line, 30 and 70 mm in front of the back edge.
3. Round every exposed corner to at least 10 mm: the hood is at head height.
4. Rivet the angle under the roof, 20 mm behind the lip, with one leg hanging down and facing the screen. Stick the LED strip on that leg.
5. Powder coat before fitting the angle and strip.

**How it fits the parts next to it.**

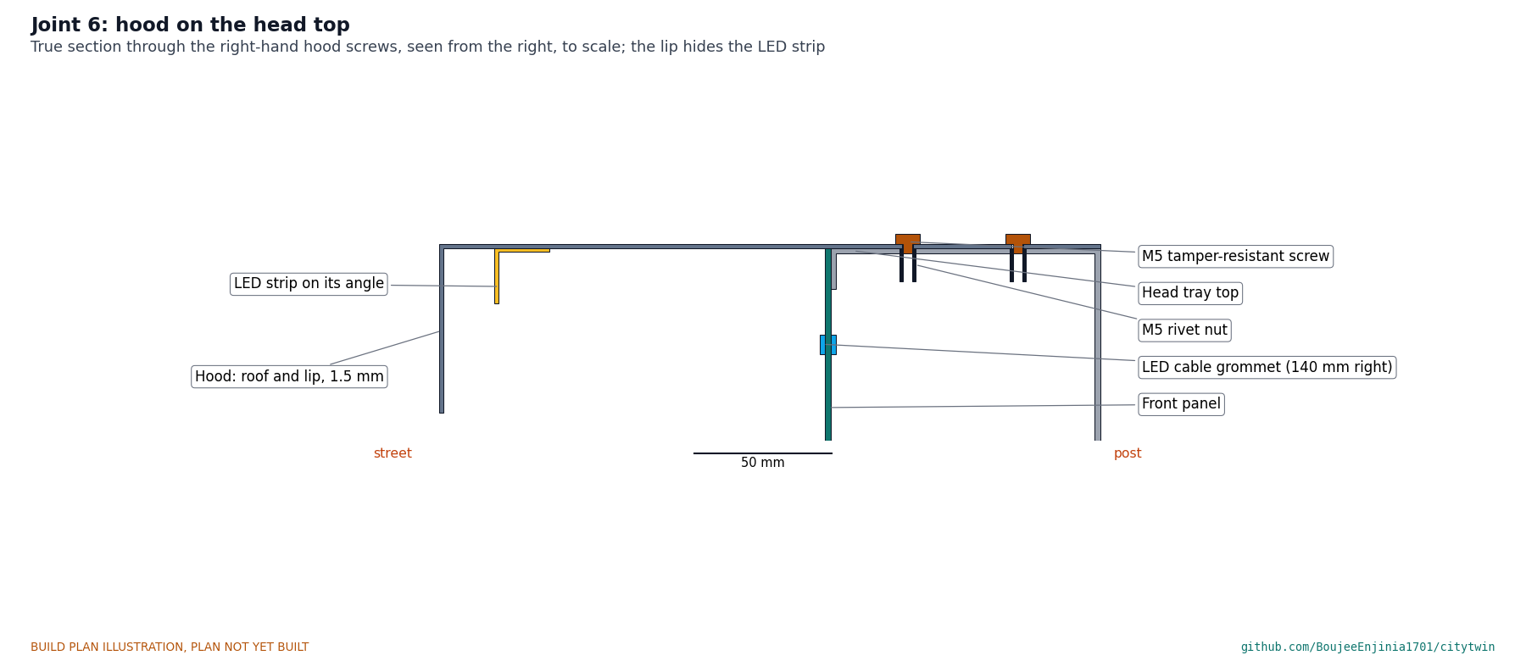
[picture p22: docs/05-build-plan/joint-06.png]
Figure 12. Joint 6: hood on the head top


*Figure 12. The roof sits on the tray top with its back edge against the post; M5 tamper-resistant screws go into the rivet nuts in the tray top. The lip hides the LED strip from the sidewalk.*

The roof reaches 140 mm in front of the head and 20 mm past it at each side. Run a bead of sealant under the roof's back edge before fitting. The LED cable runs back under the roof and into the head through a 13 mm grommet in the front panel, above the window.

**Check before moving on.** Standing 1.5 m in front of the kiosk, the LED strip cannot be seen.

### 3.6 Antenna bracket

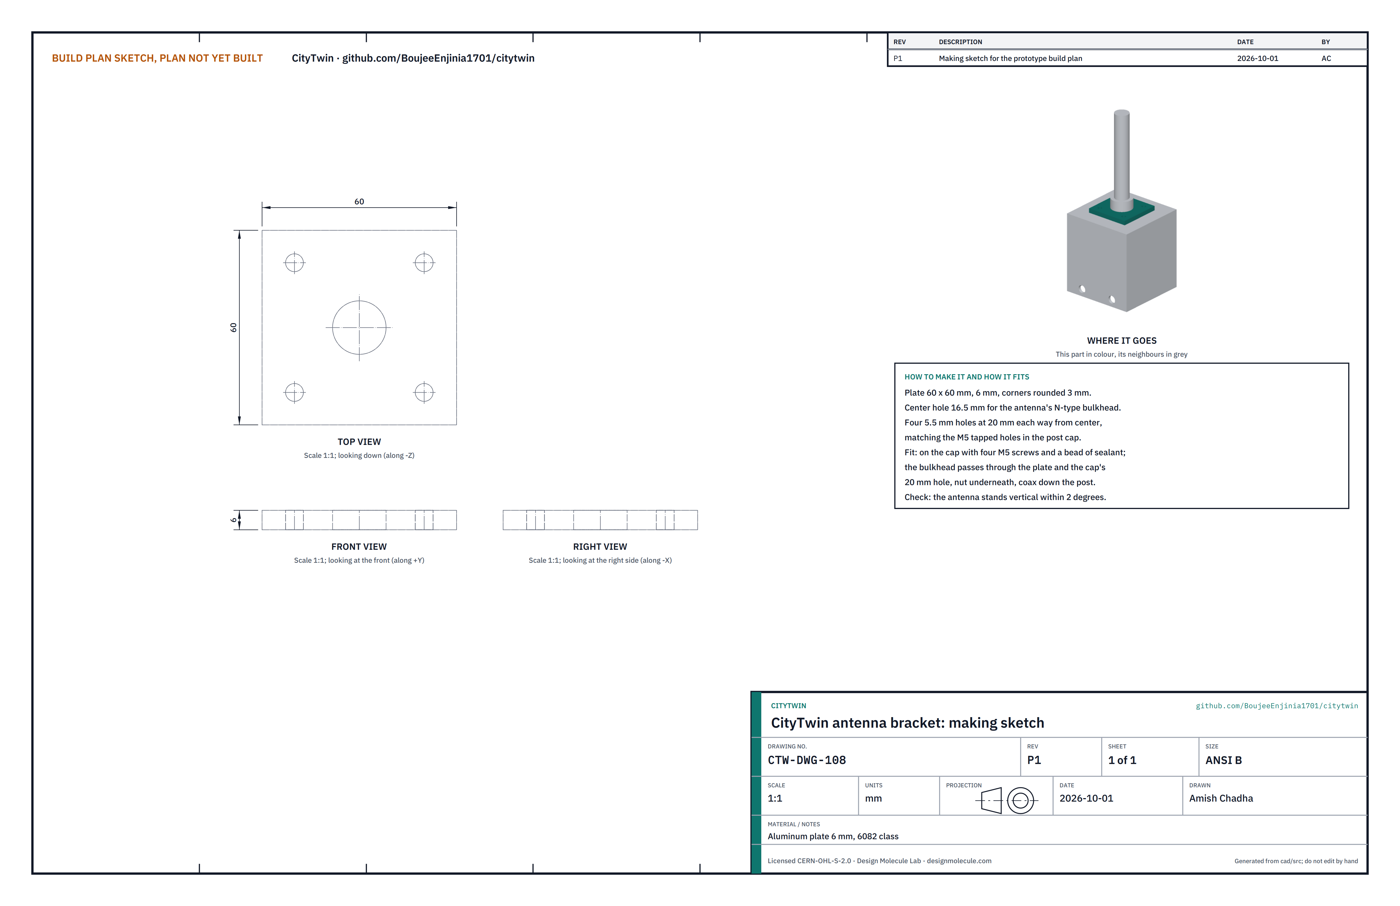
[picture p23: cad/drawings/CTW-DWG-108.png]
Figure 13. Making sketch of the antenna bracket


*Figure 13. Antenna bracket making sketch (CTW-DWG-108).*

**What it is and what it is made from.** A small plate that holds the TwinKit antenna on the post top. Aluminum plate 6 mm, 6082 class, 60 x 60 mm.

**How to make it.**

1. Cut 60 x 60 mm and round the corners to 3 mm.
2. Drill a 16.5 mm hole at the center for the antenna's N-type bulkhead.
3. Drill four 5.5 mm holes 20 mm each way from the center, matching the tapped holes in the cap.

**How it fits the parts next to it.**

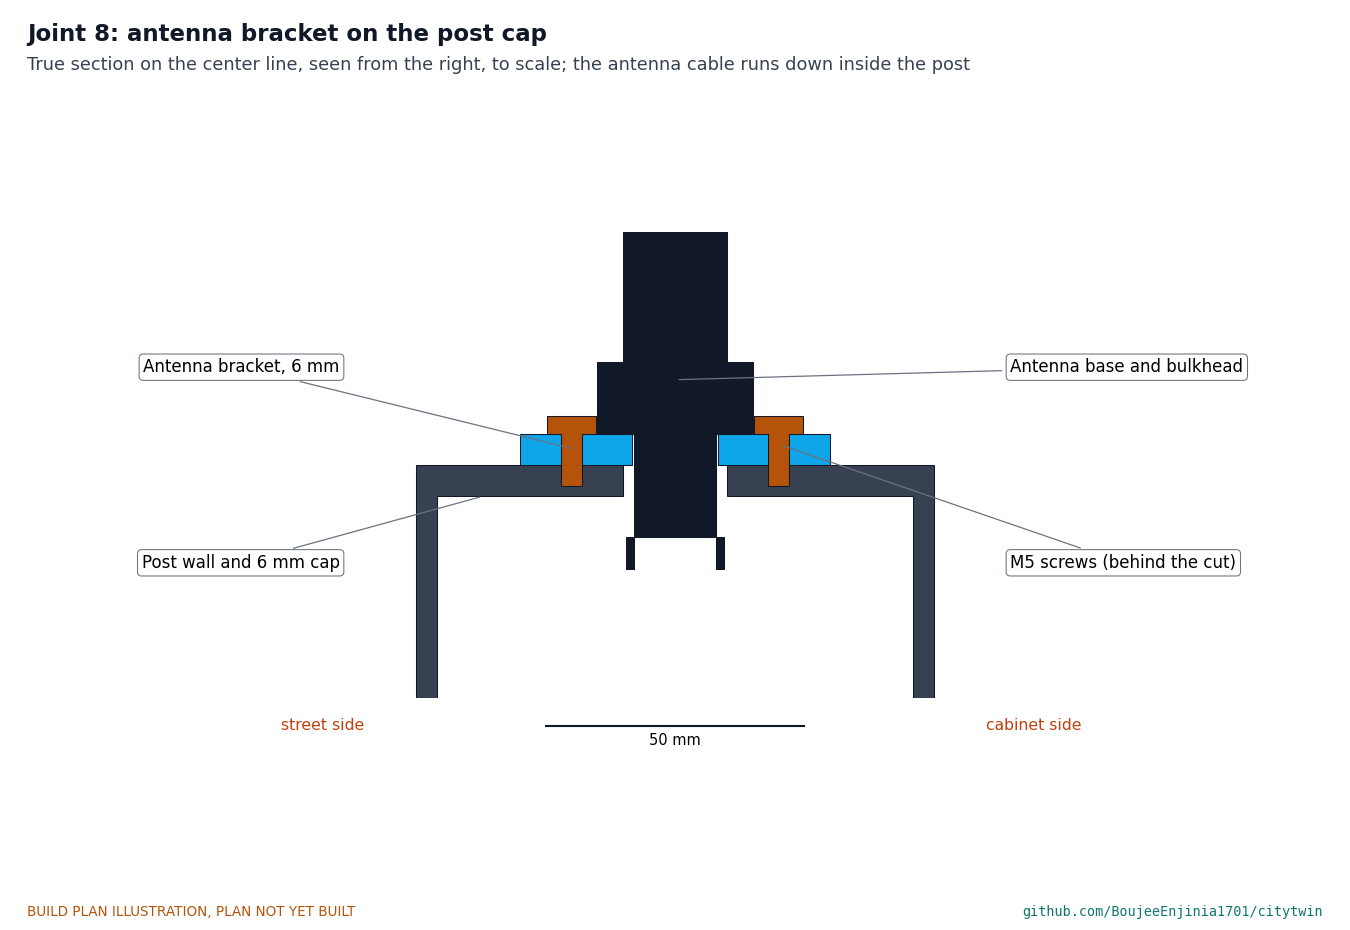
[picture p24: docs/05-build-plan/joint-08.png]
Figure 14. Joint 8: antenna bracket on the post cap


*Figure 14. The bracket sits on the cap with four M5 screws; the antenna's bulkhead passes through the bracket and the cap's 20 mm hole, with its nut underneath.*

The antenna cable is fed down inside the post to the cabinet before the bracket goes on. The antenna tip is 2.38 m up.

**Check before moving on.** The antenna stands vertical within 2 degrees.

### 3.7 Head front panel

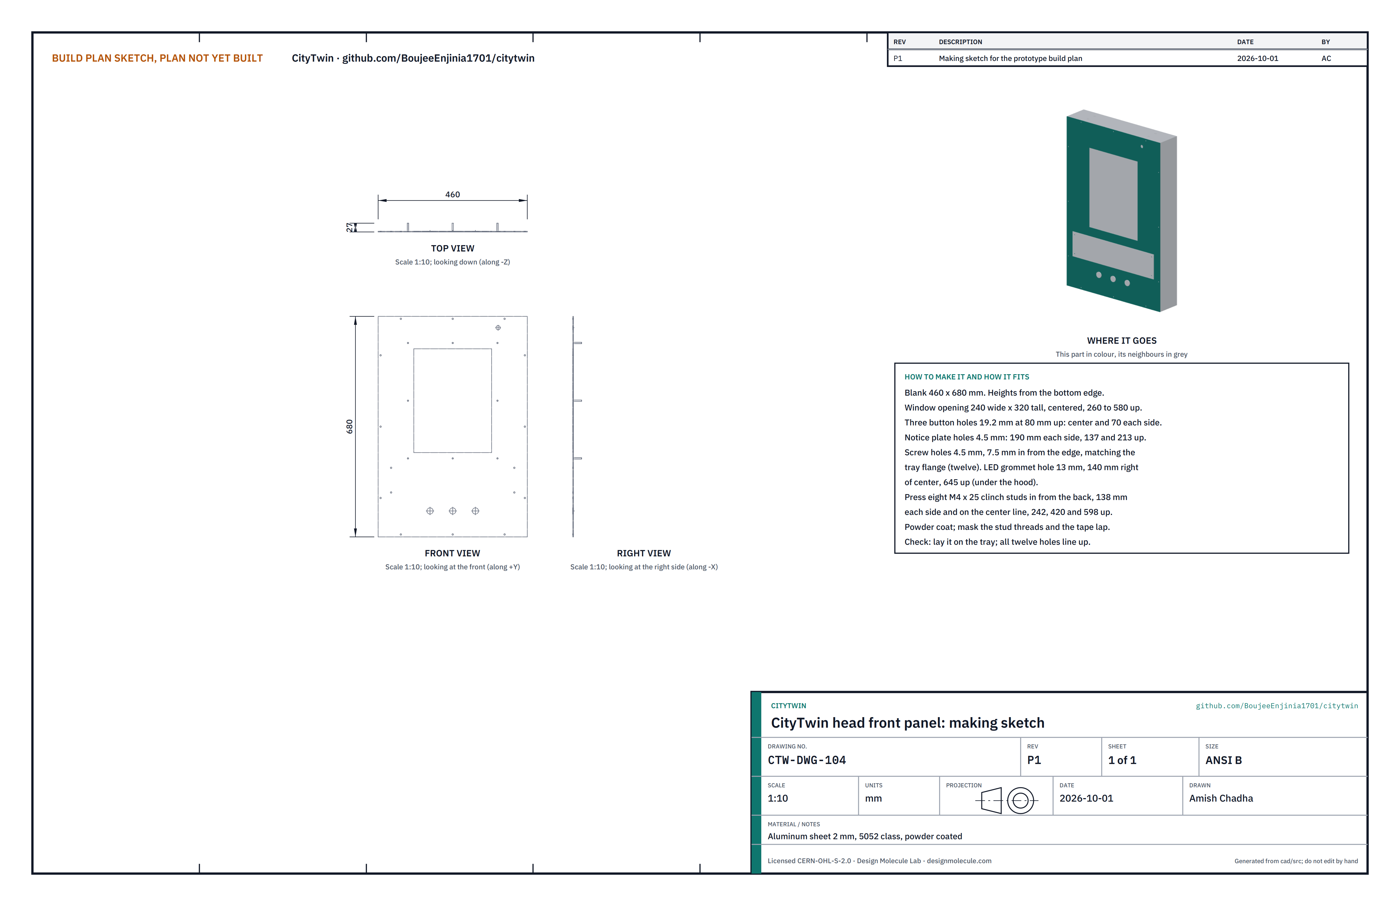
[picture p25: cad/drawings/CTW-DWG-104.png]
Figure 15. Making sketch of the head front panel


*Figure 15. Head front panel making sketch (CTW-DWG-104).*

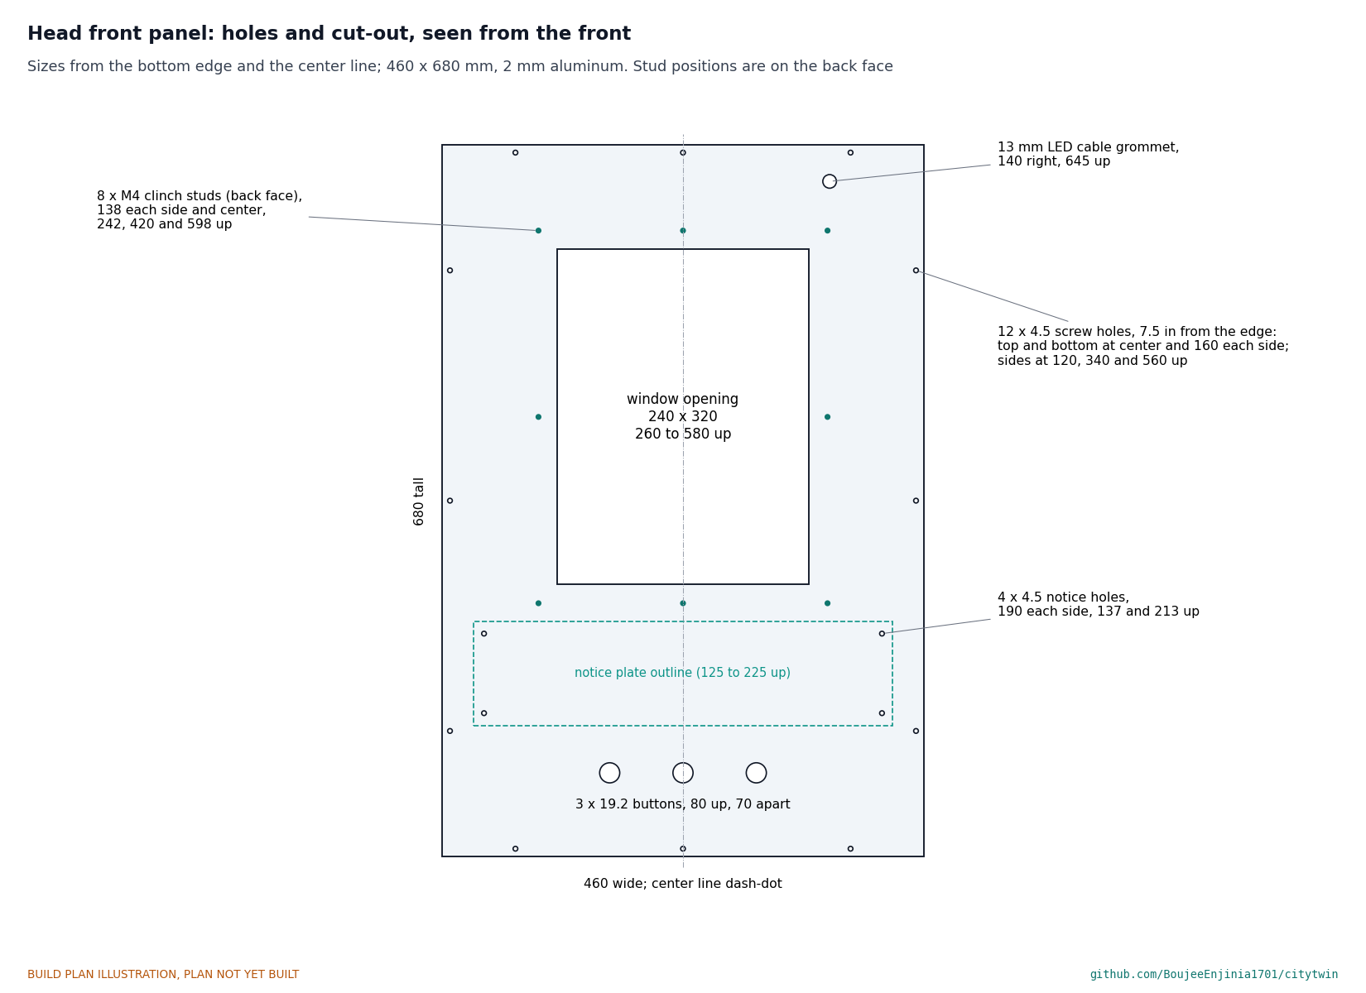
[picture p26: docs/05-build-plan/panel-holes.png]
Figure 16. Holes and cut-out in the front panel


*Figure 16. Every hole and the window opening, seen from the front, measured up from the bottom edge and sideways from the center line.*

**What it is and what it is made from.** The removable face of the head that carries the window, the screen, the buttons and the notice plate. Aluminum sheet 2 mm, 5052 class, 460 x 680 mm, powder coated.

**How to make it.**

1. Cut the blank to 460 x 680 mm and mark the center line and the bottom edge.
2. Cut the window opening 240 wide and 320 mm tall, centered, from 260 to 580 mm up.
3. Drill three 19.2 mm button holes 80 mm up: one on the center line and one 70 mm each side.
4. Drill four 4.5 mm notice plate holes, 190 mm each side of the center line, at 137 and 213 mm up.
5. Drill twelve 4.5 mm screw holes 7.5 mm in from the edge, matching the tray flange (Figure 16).
6. Drill a 13 mm hole 140 mm right of the center line, 645 mm up, for the LED cable grommet.
7. Press eight M4 x 25 mm clinch studs in from the back: 138 mm each side of the center line and on it, at 242, 420 and 598 mm up.
8. Powder coat, masking the stud threads and the 8 mm band round the opening where the glazing tape goes.

**How it fits the parts next to it.**

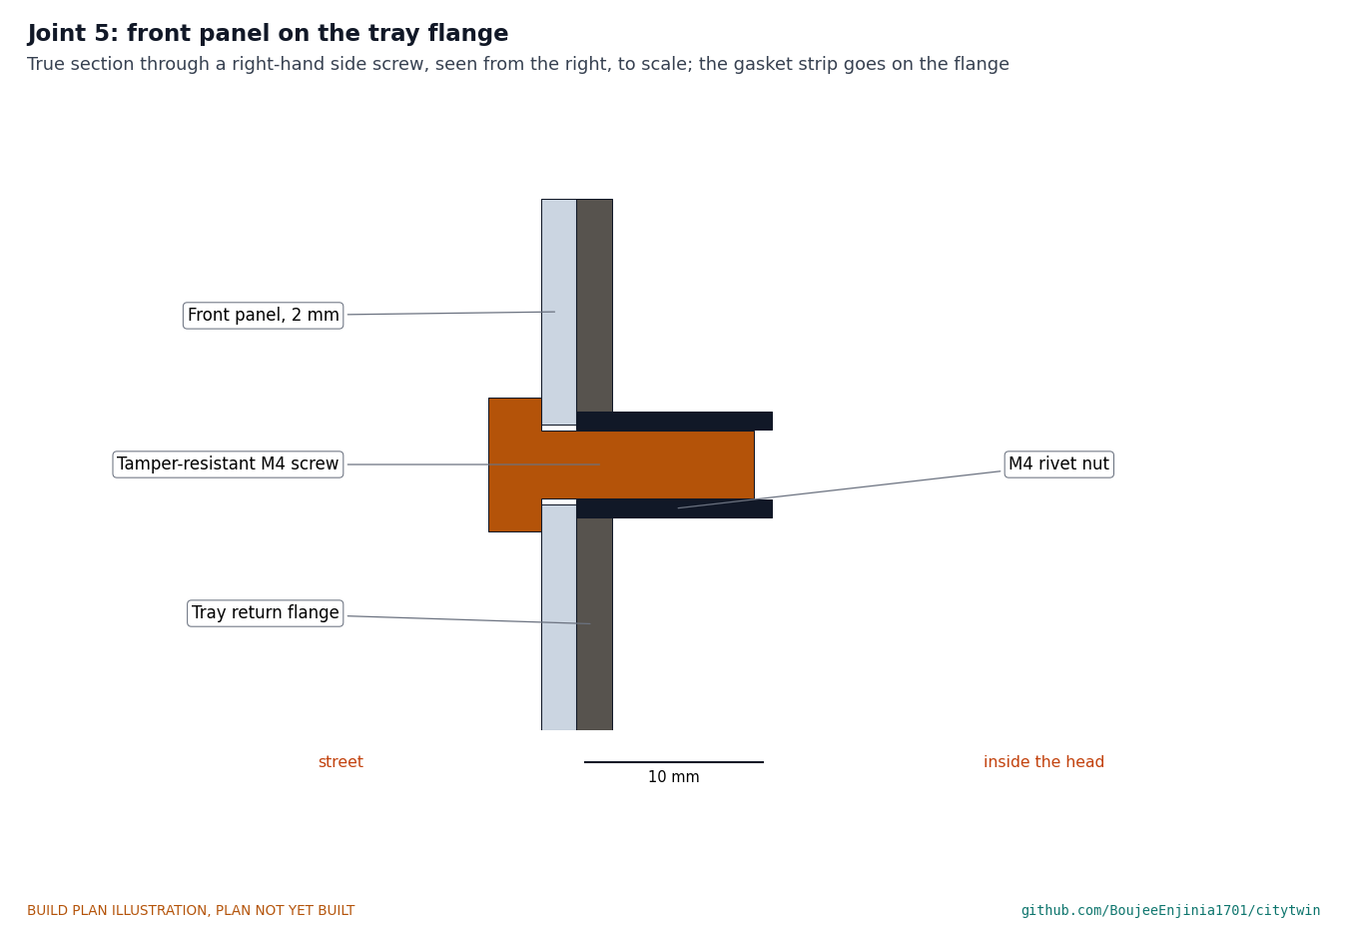
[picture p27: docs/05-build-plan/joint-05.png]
Figure 17. Joint 5: front panel on the tray flange


*Figure 17. The panel sits on the tray's flange with a gasket strip between them; a tamper-resistant M4 screw goes through the panel into the rivet nut in the flange.*

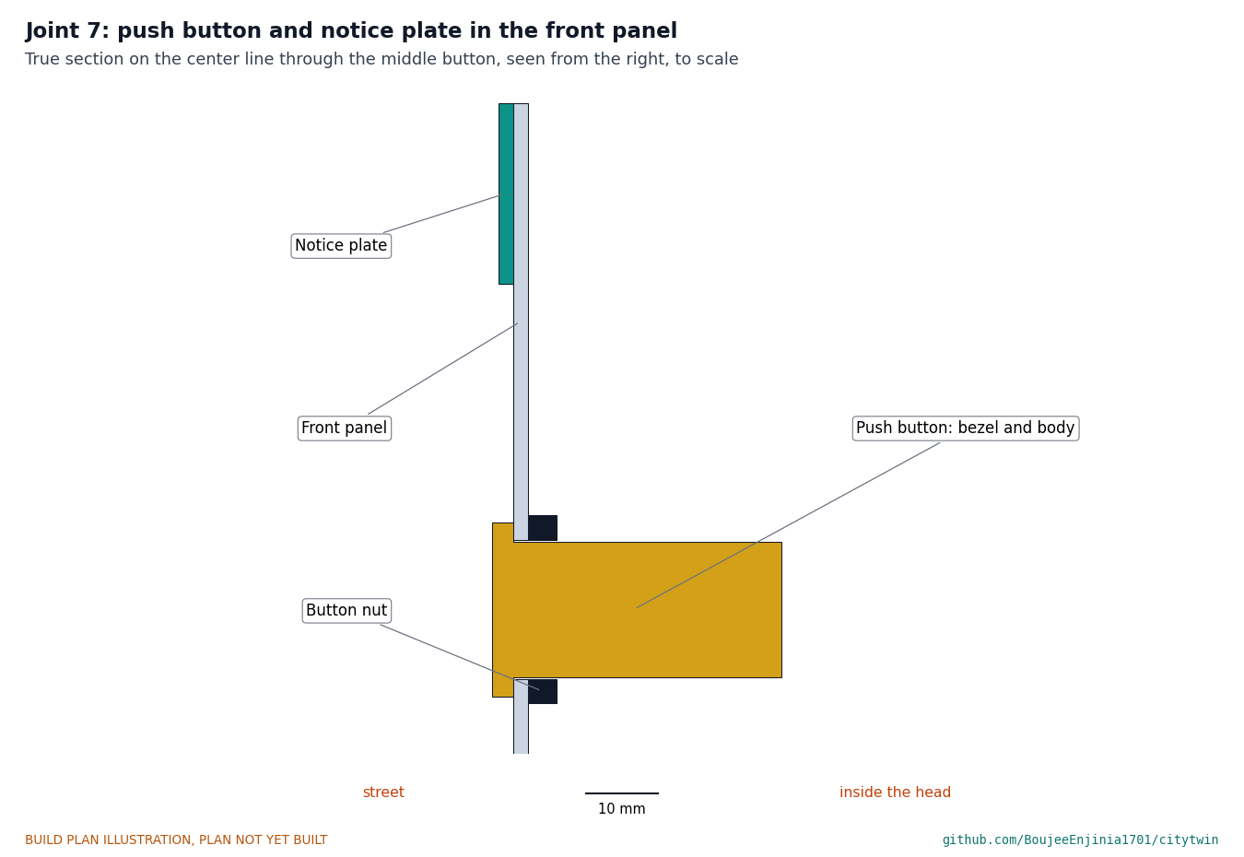
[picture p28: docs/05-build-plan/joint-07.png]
Figure 18. Joint 7: push button in the front panel


*Figure 18. Each button's bezel sits on the outside of the panel and its own nut clamps it from inside. The notice plate lies flat on the outside above the buttons.*

The panel closes the tray's open front. The window and screen stack on its back (section 3.9), the buttons and notice plate on its front.

**Check before moving on.** Laid on the tray, all twelve holes line up with the rivet nuts.

### 3.8 Data notice plate

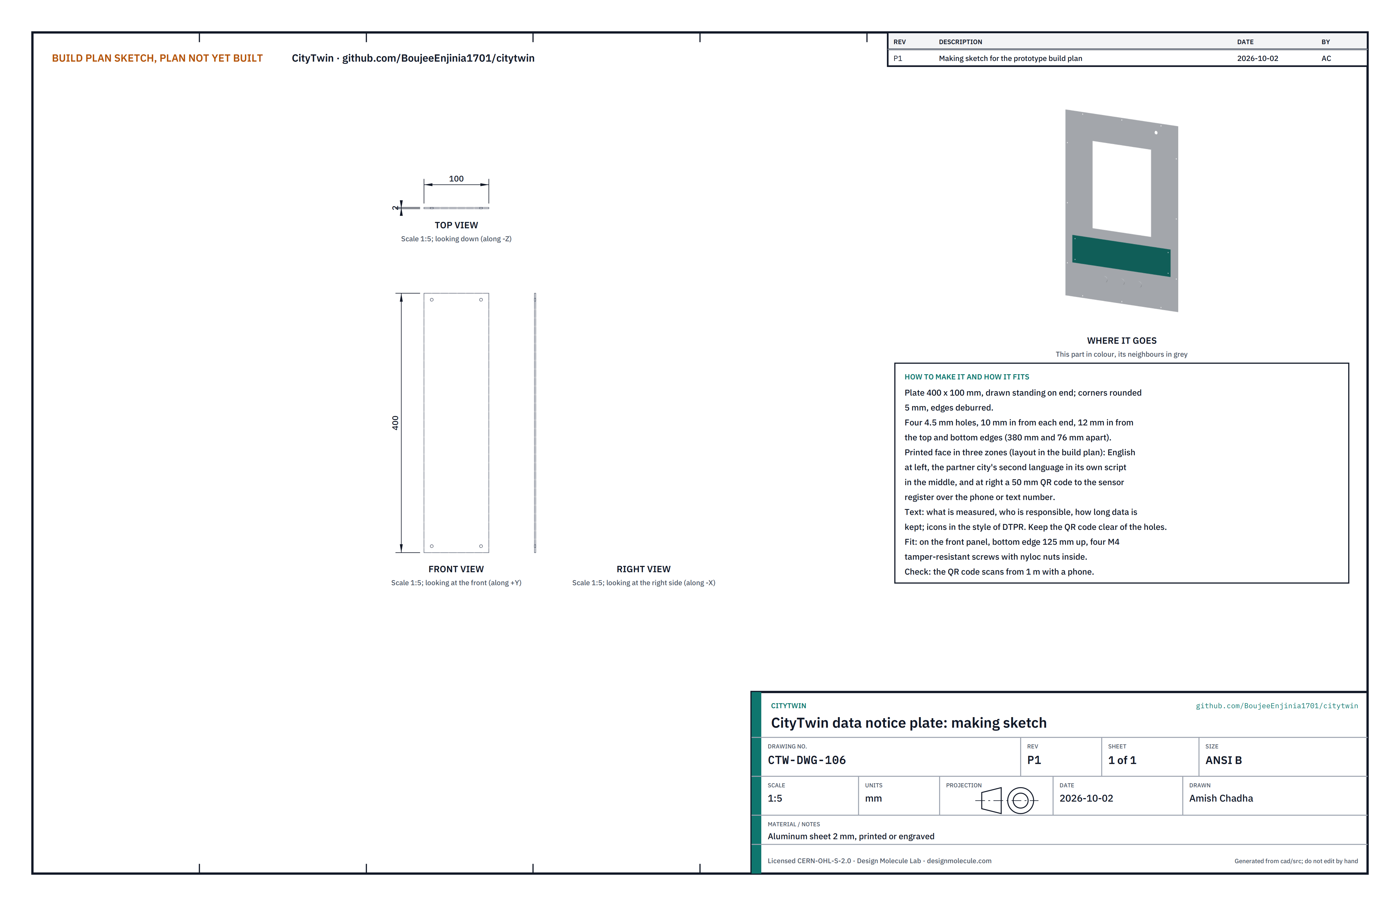
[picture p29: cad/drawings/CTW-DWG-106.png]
Figure 19. Making sketch of the data notice plate


*Figure 19. Data notice plate making sketch (CTW-DWG-106).*

**What it is and what it is made from.** The plate that tells a passer-by what is measured nearby, who is responsible, how long data is kept, and where to read more. Aluminum sheet 2 mm, 400 x 100 mm, printed or engraved by a sign maker.

**How to make it.**

1. Have the sign maker print or engrave the content in three zones (Figure 19a): English at the left; the same text in the partner city's most widely spoken other language, in its own script, in the middle; and at the right a QR code 50 mm square for the sensor register, over a phone or text number. The text says what is measured, who is responsible and how long data is kept, with icons in the style of the open DTPR standard.
2. Keep the QR code at least 25 mm square (50 mm as drawn) and clear of the holes.
3. Round the corners to 5 mm and drill four 4.5 mm holes, 10 mm in from each end and 12 mm in from the top and bottom edges.

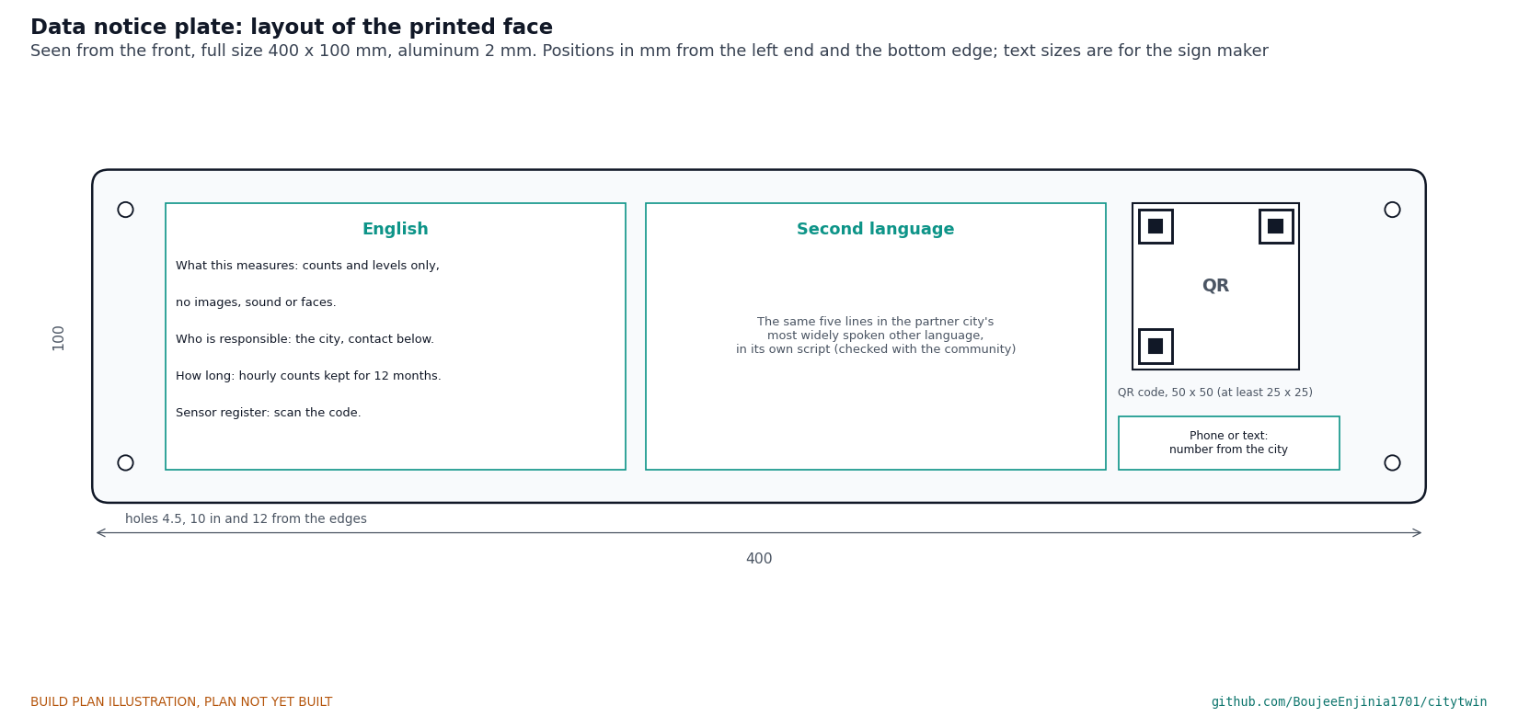
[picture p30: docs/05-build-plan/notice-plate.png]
Figure 19a. Layout of the printed face of the notice plate


*Figure 19a. Layout of the notice plate: English, second language, QR code and phone or text number.*

**How it fits the parts next to it.** The plate lies flat on the front panel with its bottom edge 125 mm up, held by four M4 tamper-resistant screws with nyloc nuts inside the panel (Figure 18).

**Check before moving on.** The QR code scans from 1 m with a phone, and a reader of the second language confirms the text.

### 3.9 Display carrier, with the window and screen

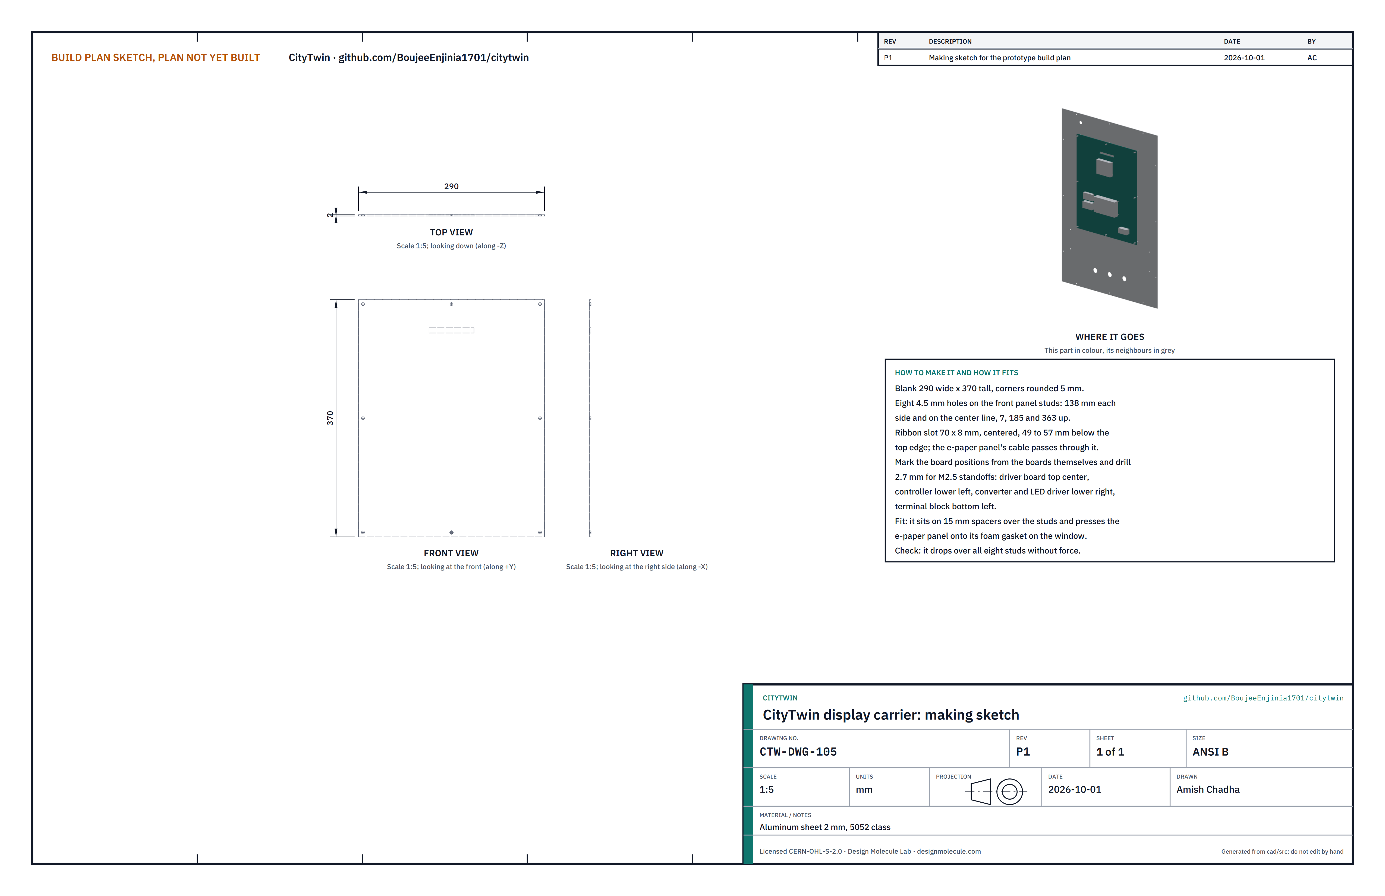
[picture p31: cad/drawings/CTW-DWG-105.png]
Figure 20. Making sketch of the display carrier


*Figure 20. Display carrier making sketch (CTW-DWG-105).*

**What it is and what it is made from.** A flat plate on the front panel's studs that holds the e-paper panel against the window and carries the electronics of the head. Aluminum sheet 2 mm, 5052 class, 290 x 370 mm.

**How to make it.**

1. Cut 290 x 370 mm and round the corners to 5 mm.
2. Drill eight 4.5 mm holes on the stud positions: 138 mm each side of the center line and on it, at 7, 185 and 363 mm up from the bottom edge.
3. Cut a 70 x 8 mm slot on the center line, 49 to 57 mm below the top edge, for the e-paper panel's flat cable.
4. Lay the boards on the back face, as seen from behind with the slot at the top: the driver board just below the slot; the controller lower right; the 5 V converter and LED driver lower left; the terminal block at the bottom right. Mark their holes through the boards and drill 2.7 mm for M2.5 standoffs.

**How it fits the parts next to it.**

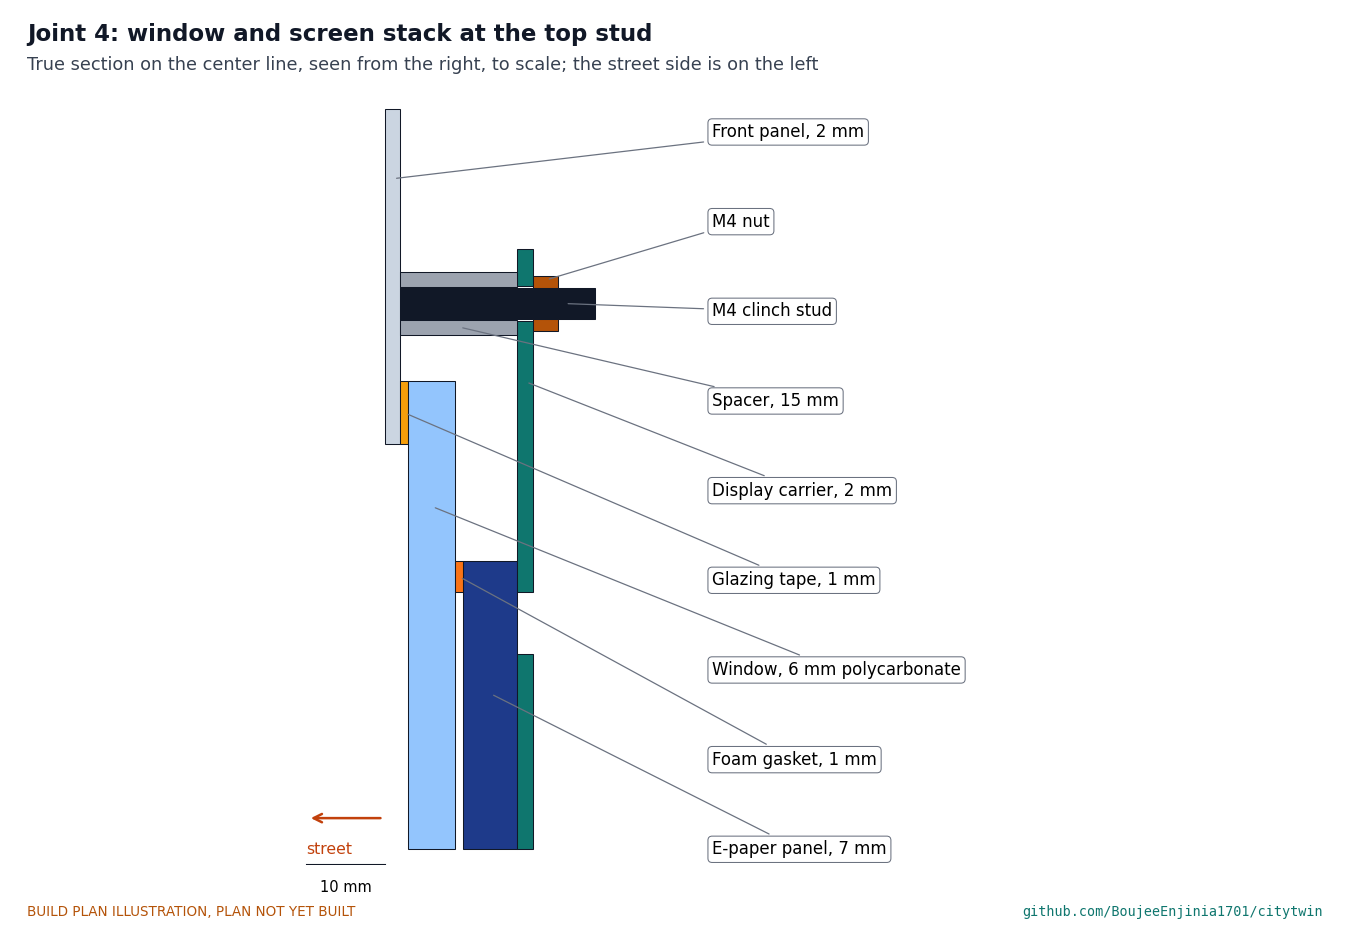
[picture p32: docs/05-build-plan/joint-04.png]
Figure 21. Joint 4: window and screen stack at the top stud


*Figure 21. From the street side: front panel, glazing tape, window, foam gasket, e-paper panel, carrier. The carrier sits on 15 mm spacers over the studs and its nuts press the panel onto the gasket.*

The window is 6 mm polycarbonate, 256 x 336 mm. It is bonded inside the front panel by a 1 mm acrylic glazing tape on its 8 mm lap round the opening. A 1 mm foam gasket strip runs round the e-paper panel's border, between the panel and the window, so the glass never touches the window directly. The 15 mm spacers set the stack: tape, window, gasket and panel add up to 15 mm, so the carrier just clamps the panel when the nuts are snug.

#### 3.9.1 Wiring

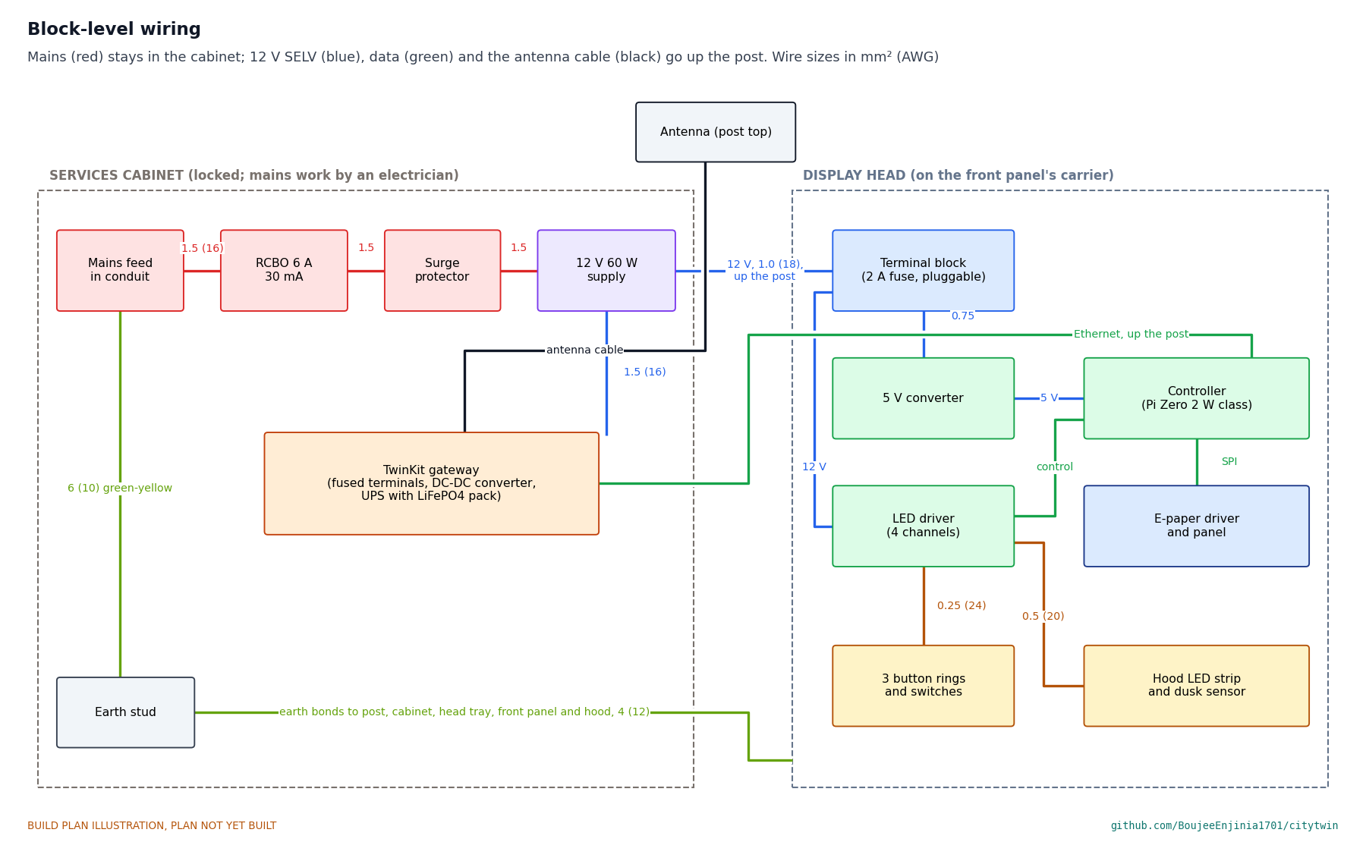
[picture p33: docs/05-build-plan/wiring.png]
Figure 22. Block-level wiring


*Figure 22. Block-level wiring with wire sizes. Mains (red) stays in the cabinet; only 12 V, data and the antenna cable go up the post.*

The low-voltage wiring in the head is yours to do; the mains wiring in the cabinet is the electrician's. Use stranded copper and a ferrule on every screw terminal.

1. Cabinet (electrician): mains feed through the conduit gland to the RCBO, then the surge protector, then the 12 V supply, in 1.5 mm² (16 AWG) wire; earth to the earth stud in 6 mm² (10 AWG).
2. Cabinet: 12 V supply output to the TwinKit gateway's fused terminals, 1.5 mm².
3. Up the post: one 2-core 1.0 mm² (18 AWG) cable from the 12 V supply to the head's terminal block; one outdoor Ethernet cable from the gateway to the controller; the antenna cable from the gateway's antenna socket to the antenna.
4. Head: terminal block (with its 2 A fuse) to the 5 V converter and the LED driver, 0.75 mm²; 5 V converter to the controller; driver board to the e-paper panel's flat cable.
5. Head: LED driver to the three button rings, 0.25 mm² (24 AWG), and to the hood LED strip, 0.5 mm² (20 AWG) through the front panel grommet; button switches and the dusk sensor to the controller's inputs.
6. Earth bonds from the cabinet's earth stud to the post, the head tray, the front panel and the hood, 4 mm² (12 AWG), by the electrician.

**Check before moving on.** With nothing powered, every wire continues end to end; the 12 V pair reads open between its cores; every wire is labelled; the cables to the front panel all pass through the pluggable terminal block, so the panel unplugs.

### 3.10 Sun shield (outdoor sites only)

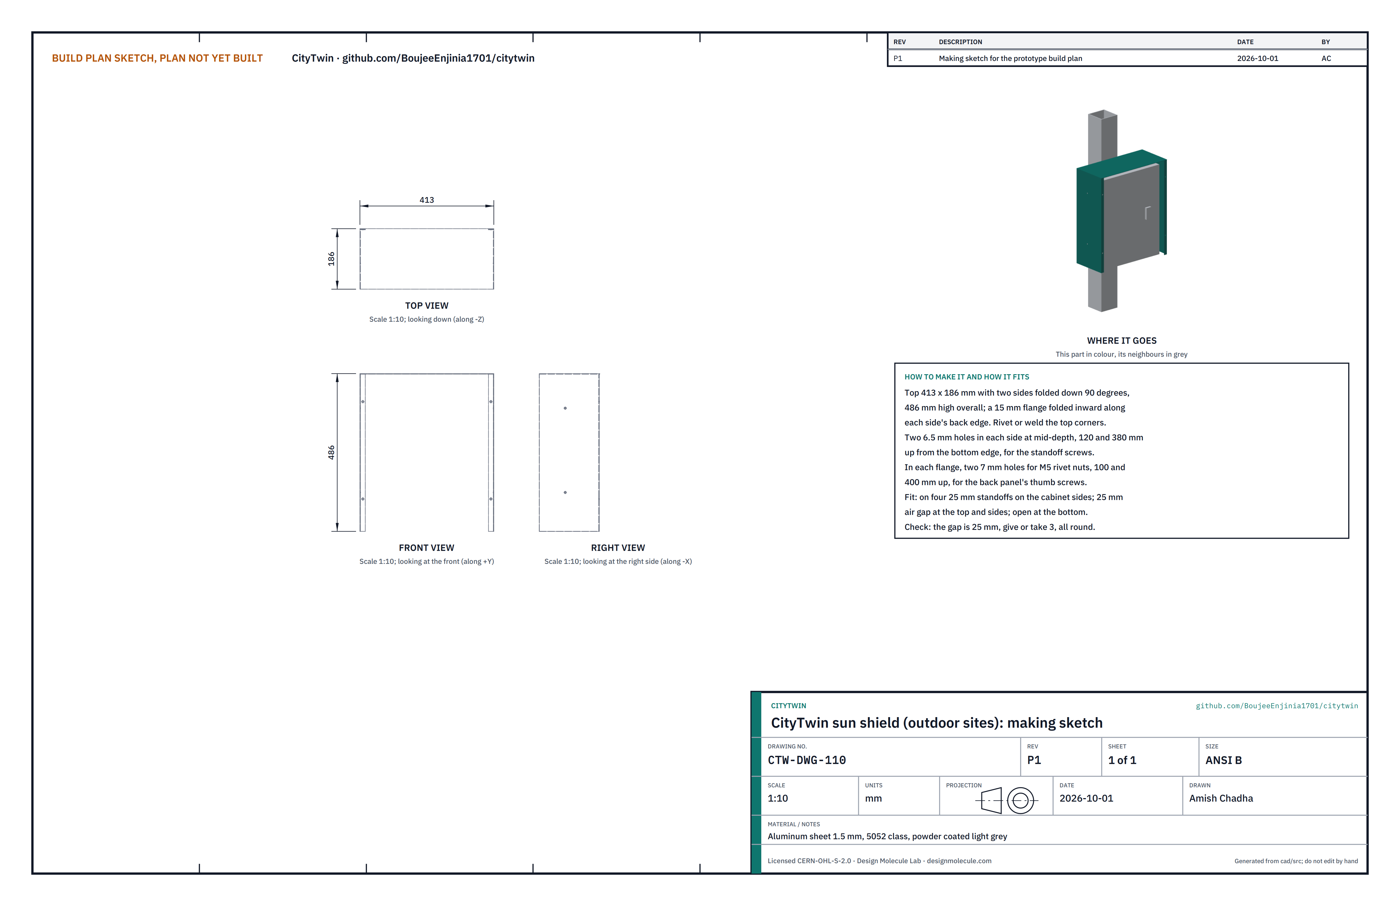
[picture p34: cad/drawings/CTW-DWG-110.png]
Figure 23. Making sketch of the sun shield


*Figure 23. Sun shield making sketch (CTW-DWG-110).*

**What it is and what it is made from.** A light grey cover over the top and sides of the cabinet that keeps direct sun off it, fitted only on outdoor sites. Aluminum sheet 1.5 mm, 5052 class, powder coated light grey.

**How to make it.**

1. Fold a top 413 x 186 mm with two sides down 90 degrees, 486 mm high overall.
2. Fold a 15 mm flange inward along the back edge of each side, and rivet or weld the top corners.
3. Drill two 6.5 mm holes in each side at mid-depth, 120 and 380 mm up from the bottom edge.
4. Drill two 7 mm holes in each flange, 100 and 400 mm up, and set M5 rivet nuts in them.
5. Powder coat light grey.

**How it fits the parts next to it.**

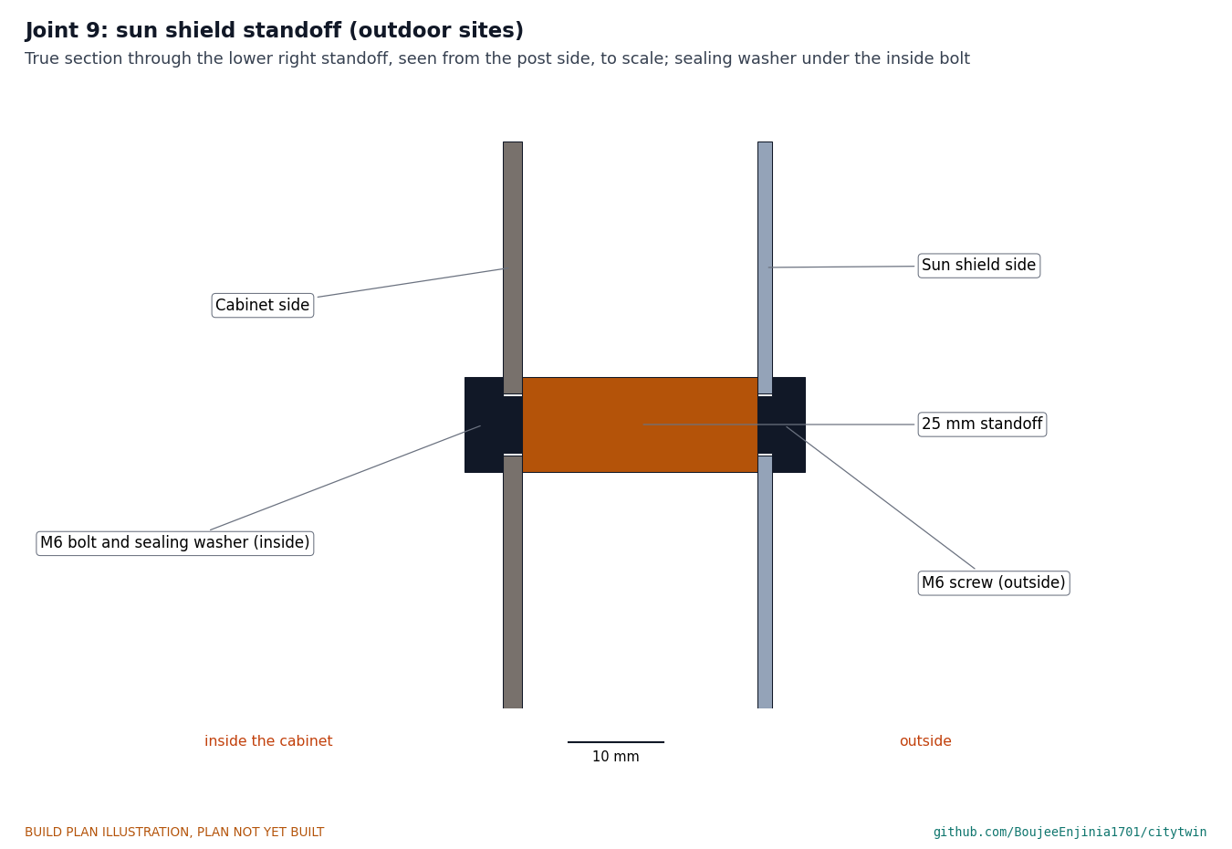
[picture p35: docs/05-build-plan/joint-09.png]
Figure 24. Joint 9: sun shield standoff


*Figure 24. A 25 mm standoff is bolted through the cabinet side with a sealing washer under the bolt head inside; an M6 screw holds the shield side to it from outside.*

The shield stands 25 mm off the cabinet's top, sides and back, and is open at the bottom, so air rises through the gap.

**Check before moving on.** On a trial fit the gap is 25 mm, give or take 3 mm, all round.

### 3.11 Shield back panel (outdoor sites only)

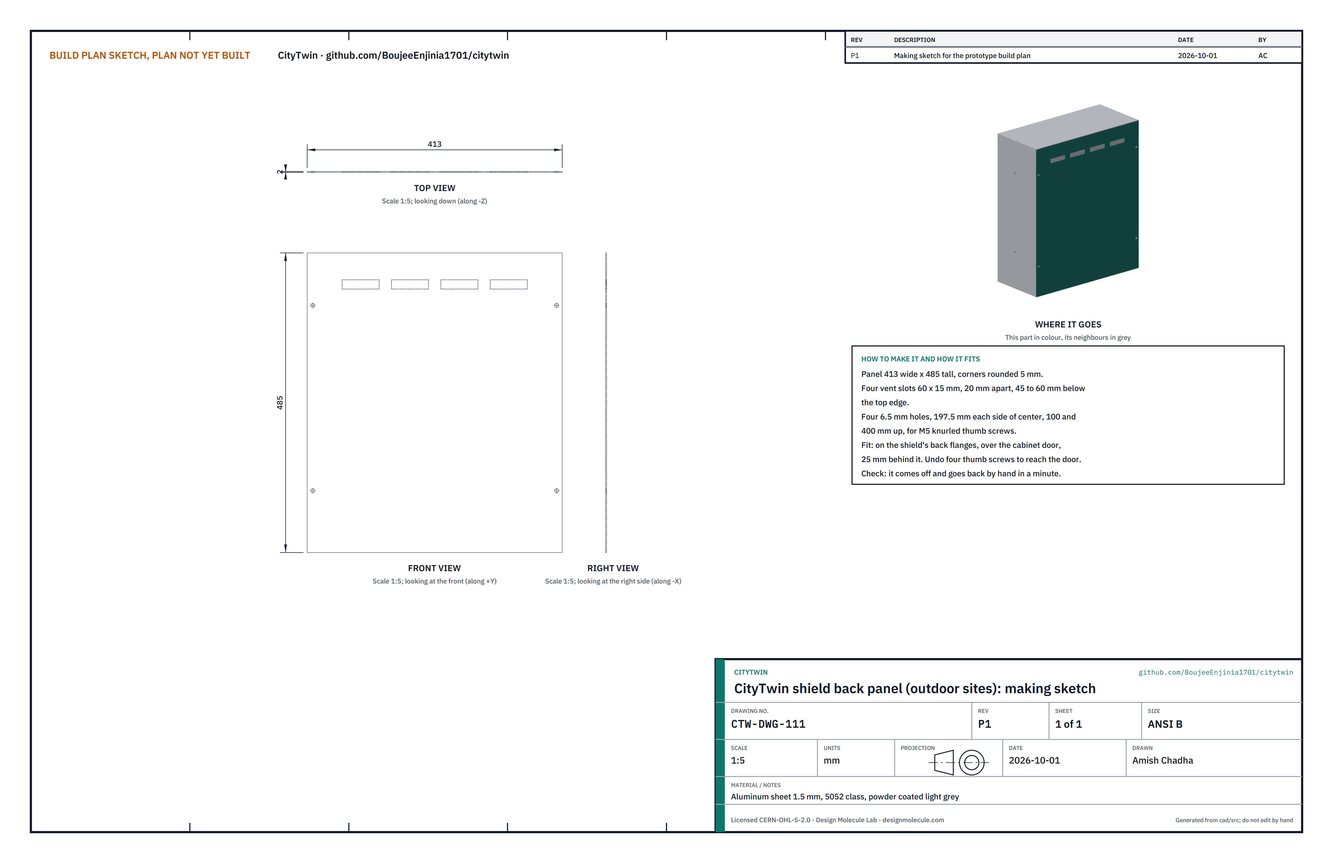
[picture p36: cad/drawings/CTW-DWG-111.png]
Figure 25. Making sketch of the shield back panel


*Figure 25. Shield back panel making sketch (CTW-DWG-111).*

**What it is and what it is made from.** The removable part of the shield over the cabinet door. Aluminum sheet 1.5 mm, 5052 class, 413 x 485 mm, powder coated light grey.

**How to make it.**

1. Cut 413 x 485 mm and round the corners to 5 mm.
2. Cut four vent slots 60 x 15 mm, 20 mm apart, about 45 to 60 mm below the top edge.
3. Drill four 6.5 mm holes 197.5 mm each side of the center line, at 100 and 400 mm up.
4. Powder coat light grey.

**How it fits the parts next to it.** The panel lies on the shield's two back flanges, 25 mm behind the cabinet door, held by four M5 knurled thumb screws into the flange rivet nuts. Undo the thumb screws to reach the locked door.

**Check before moving on.** It comes off and goes back by hand in about a minute.

### 3.12 Bought components

Buy to specification, not brand. Line numbers are those of the bill of materials.

- **Anchors (line 1).** Four M16 anchors with nuts and 34 mm washers, sized by the structural design of the footing; for the bench build, chemical anchors in a precast concrete block of about 700 x 700 x 300 mm.
- **Window (line 4).** 6 mm UV-stabilized, anti-glare polycarbonate cut to 256 x 336 mm, edges smooth.
- **E-paper display (line 5).** 13.3 in color E Ink Spectra 6 panel, 1600 x 1200 px, with its driver board; outline about 210 x 290 x 7 mm.
- **Controller and head modules (line 6).** Raspberry Pi Zero 2 W class board with an industrial microSD card, a USB Ethernet adapter and a real-time clock; a 12 V to 5 V, 3 A buck converter; a 4-channel low-side LED driver module; a pluggable 6-way terminal block with a 2 A fuse.
- **Push buttons (line 7).** Three 19 mm stainless vandal-resistant momentary buttons with LED rings, 24 mm bezel, IP65.
- **Hood light (line 9).** 12 V warm white LED strip of about 2 W, 300 mm long, and a dusk sensor.
- **Cabinet (line 10).** Lockable steel cabinet 360 x 160 x 460 mm, IP55, with a removable mounting plate on studs, two 320 mm TS35 DIN rails and an earth stud. Drill as section 3.3.
- **Mains protection (line 11).** A 6 A, 30 mA RCBO and a Type 2 surge protective device, two modules each.
- **12 V supply (line 12).** DIN rail supply, 60 W, 12 V certified SELV output, three modules.
- **TwinKit gateway (line 13).** Built from the TwinKit repository as its own drawing TWK-DWG-001 lays it out, with an antenna cable to the post-top antenna in place of its whip.
- **Antenna (line 14).** The TwinKit antenna with an N-type bulkhead base.
- **Conduit and cabling (line 15).** 32 mm conduit and a matching gland; 2-core 1.0 mm² outdoor cable; outdoor Ethernet cable; four rubber grommets for 25 mm holes in walls of 4 to 6 mm; earth bond leads.
- **Fixings, tapes and gaskets (line 21).** Stainless where outdoors: 8 M8 steel flush rivet nuts for a 4 mm wall; 8 M8 x 20 mm button-head screws with 30 mm washers; 16 M4 and 4 M5 aluminum rivet nuts; 12 M4 tamper-resistant screws (front panel); 4 M4 tamper-resistant screws with nyloc nuts (notice plate); 4 M5 tamper-resistant screws (hood); 4 M5 screws (antenna bracket); 8 M4 x 15 mm spacers and nuts; M2.5 standoffs; 1 mm acrylic glazing tape 8 mm wide; 1 mm foam gasket tape; EPDM gasket strip for the front panel flange; for outdoor sites, four M6 x 25 mm aluminum standoffs, M6 screws and bolts with sealing washers, and four M5 knurled thumb screws.

## 4. Putting it together

In each picture the parts already fitted are grey and the part being fitted is in color, with an arrow showing the way it goes in.

### Step 1: post onto the anchors

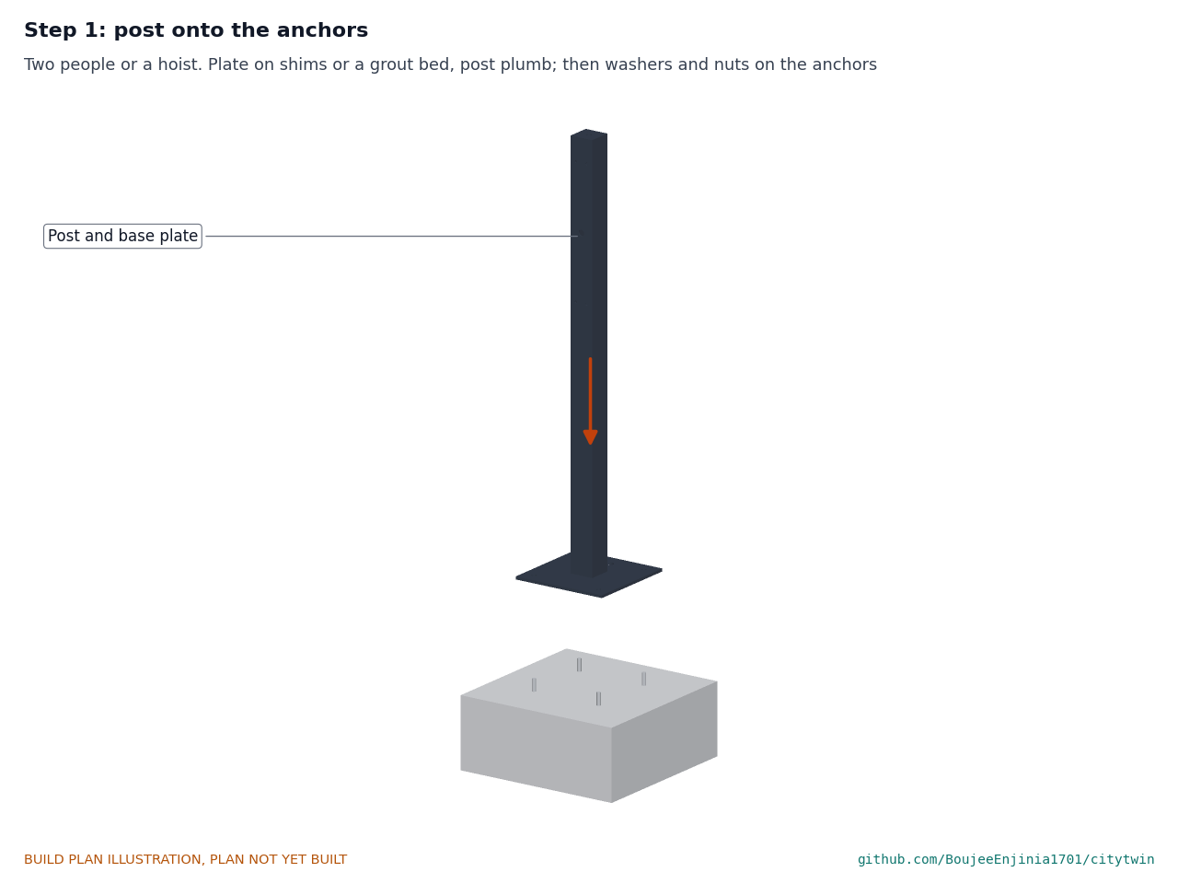
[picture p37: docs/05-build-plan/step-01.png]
Step 1


With two people or a hoist, lower the post and base plate over the anchors onto shims or a grout bed. Plumb the post with a level on two faces, then fit the washers and nuts and tighten them to the anchor maker's torque. **Hold point:** safety stop S1.

### Step 2: cabinet onto the post

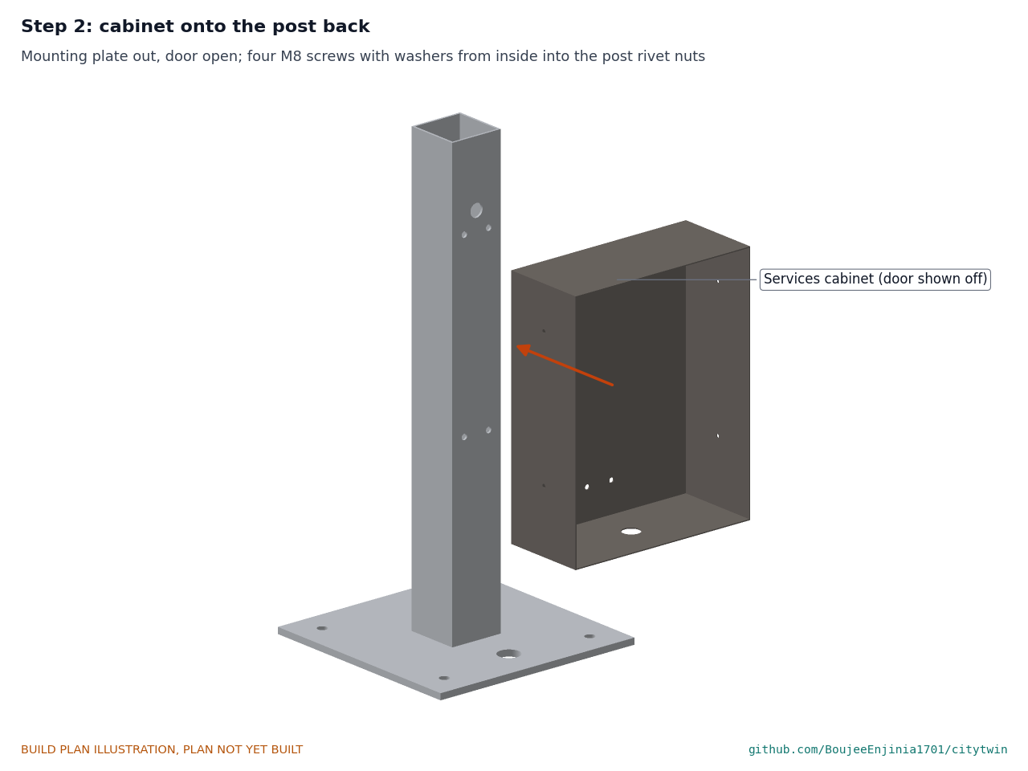
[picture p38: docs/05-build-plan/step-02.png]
Step 2


Mounting plate out, door open. Hold the cabinet flat on the post's back wall, 300 mm up, and fit four M8 screws with 30 mm washers from inside into the rivet nuts. Tighten evenly.

### Step 3: mounting plate and rails into the cabinet

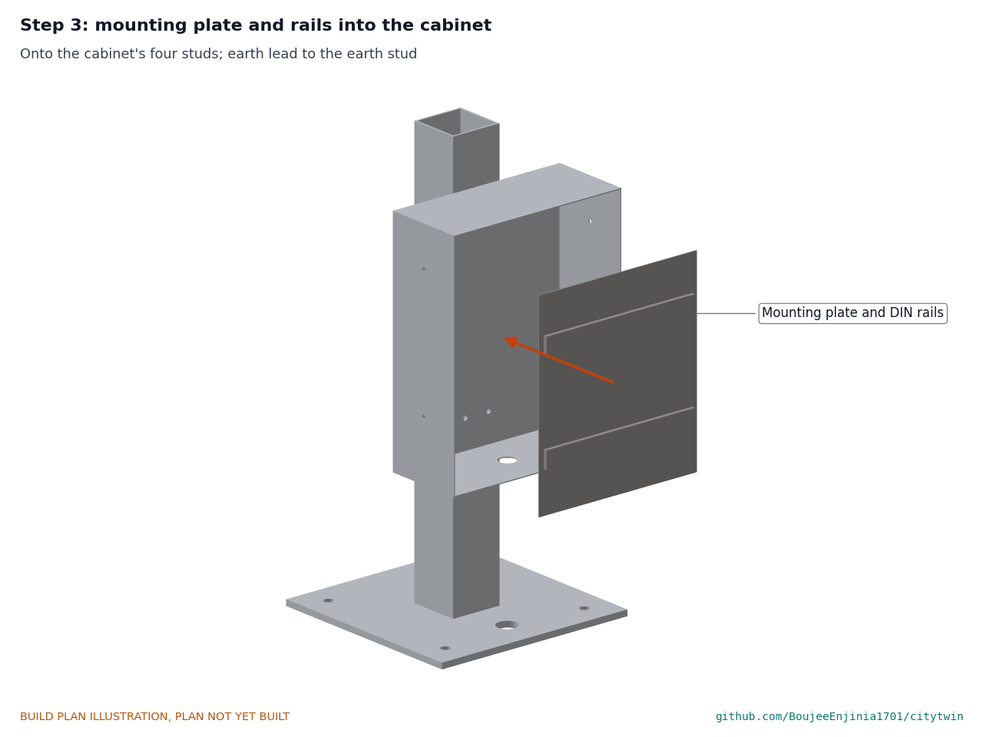
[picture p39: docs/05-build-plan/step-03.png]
Step 3


Fit the mounting plate with its two rails on its four studs and connect its earth lead to the earth stud.

### Step 4: mains protection and 12 V supply on the lower rail

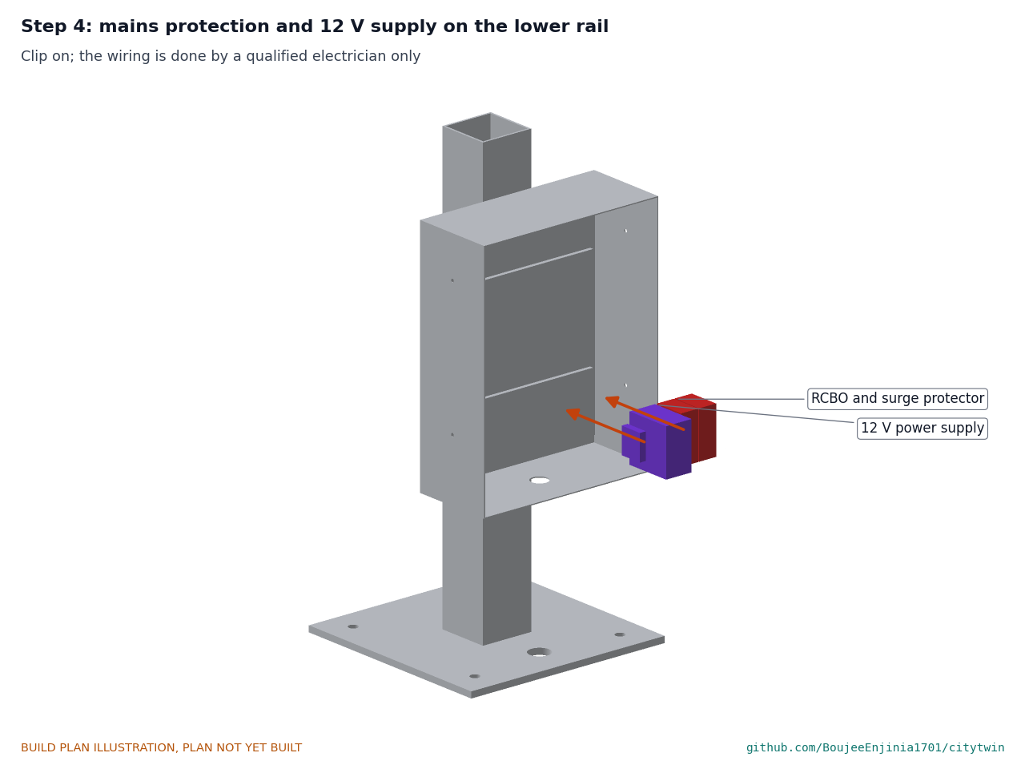
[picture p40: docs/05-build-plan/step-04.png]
Step 4


Clip the RCBO, the surge protector and the 12 V supply onto the lower rail, in that order starting from the right as you face the open door. The electrician wires them (section 3.9.1, wire 1). **Hold point:** safety stop S2.

### Step 5: TwinKit gateway on the upper rail

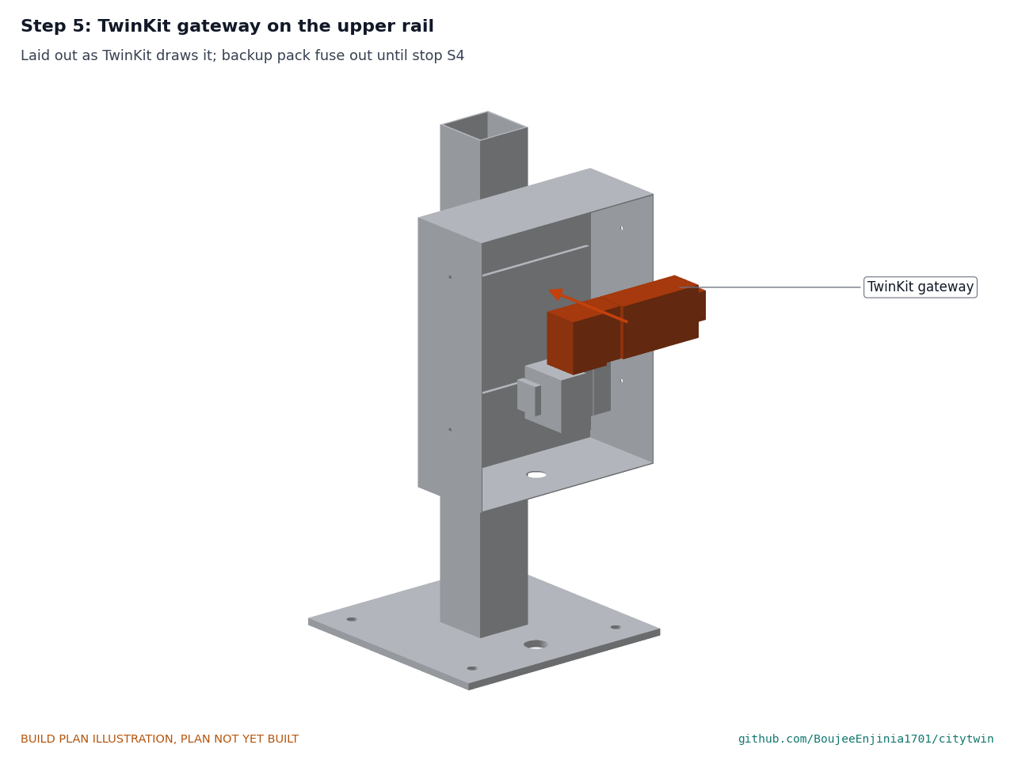
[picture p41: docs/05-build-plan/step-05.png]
Step 5


Clip the gateway's parts onto the upper rail as TwinKit lays them out, with the backup pack's fuse out; it goes in only at safety stop S4. Connect the 12 V supply to its fused terminals.

### Step 6: conduit, gland and grommets

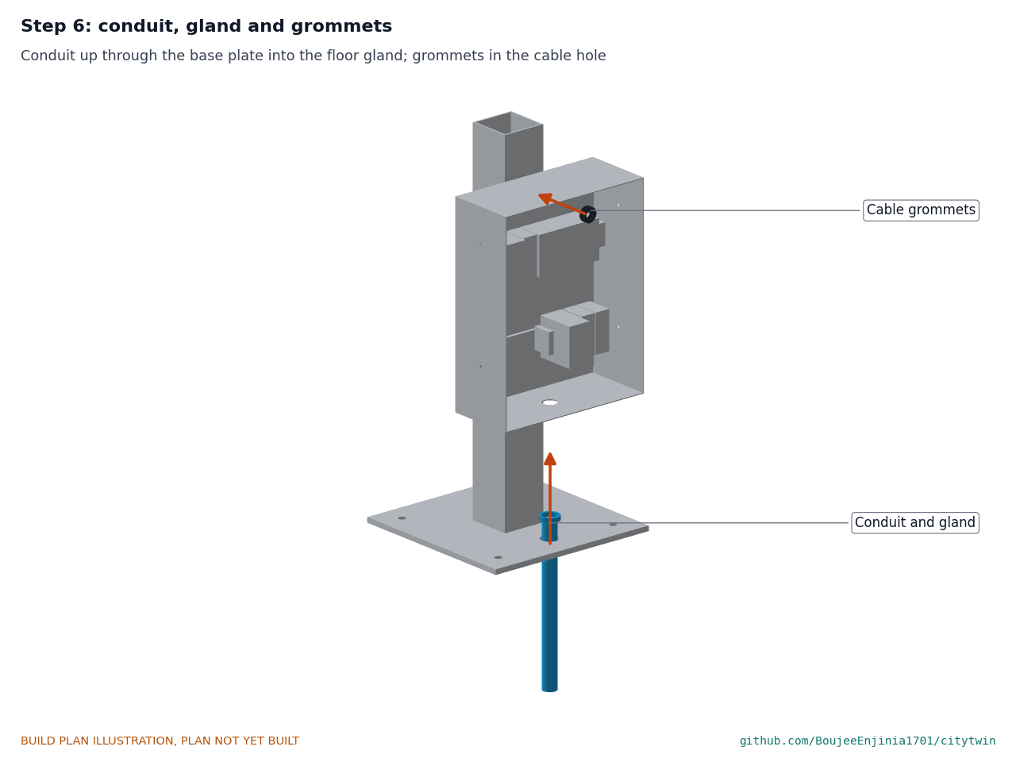
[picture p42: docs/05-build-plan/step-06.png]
Step 6


Fit the conduit gland in the cabinet floor and bring the conduit up through the base plate into it. Fit the grommets in the cable hole on both sides of the wall. Feed the 12 V cable, the Ethernet cable and the antenna cable up the post to the head and the post top. **Hold point:** safety stop S3 before the mains is first switched on.

### Step 7: head tray onto the post

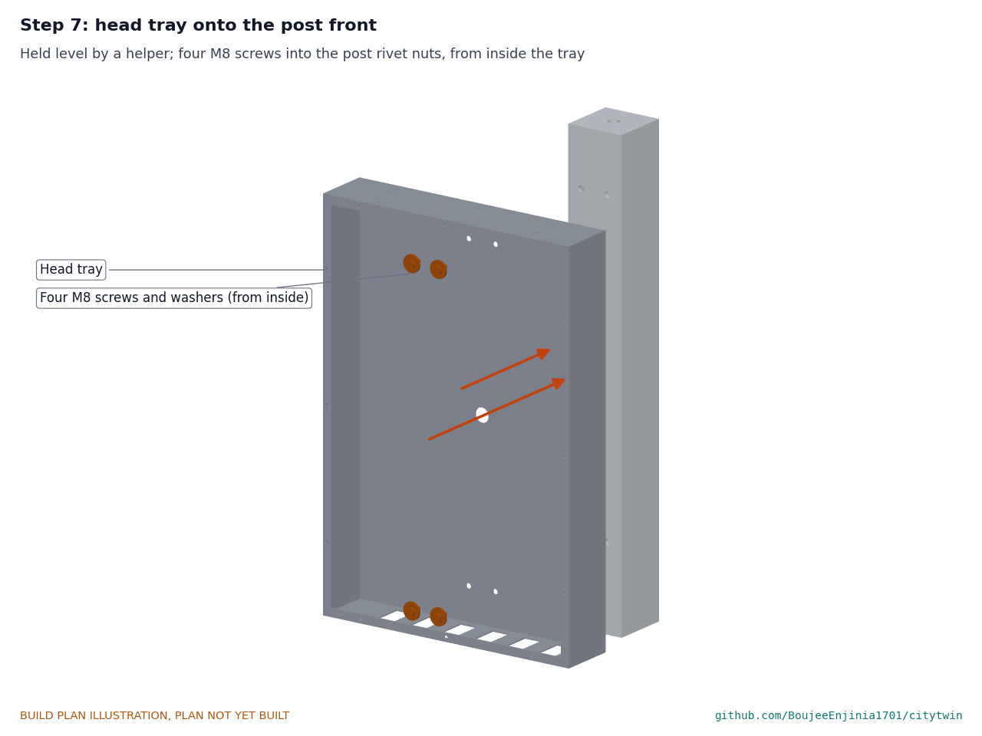
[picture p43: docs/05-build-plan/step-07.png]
Step 7


With a helper holding the tray level, bottom edge 1,040 mm up, fit four M8 screws with 30 mm washers from inside the tray into the rivet nuts. Fit the grommet in the head's cable hole and pull the cables through.

### Step 8: hood onto the head top

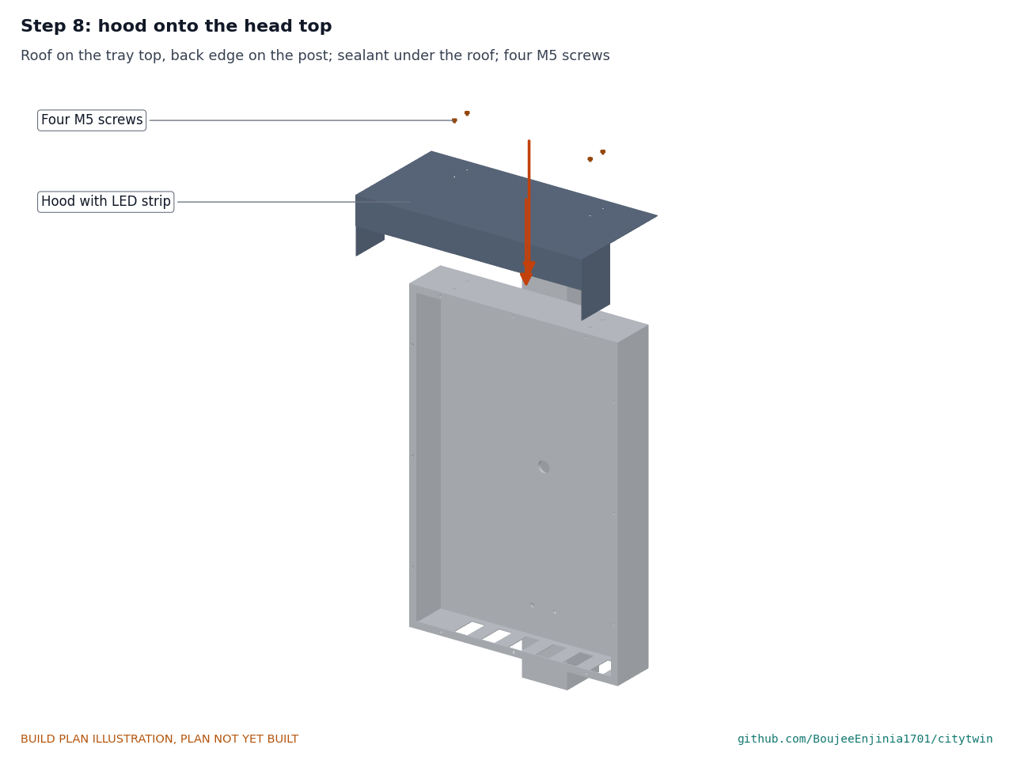
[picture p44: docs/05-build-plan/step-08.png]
Step 8


Run sealant along the roof's back edge, set the roof on the tray top against the post, and fit four M5 tamper-resistant screws into the rivet nuts.

### Step 9: antenna bracket and antenna on the post cap

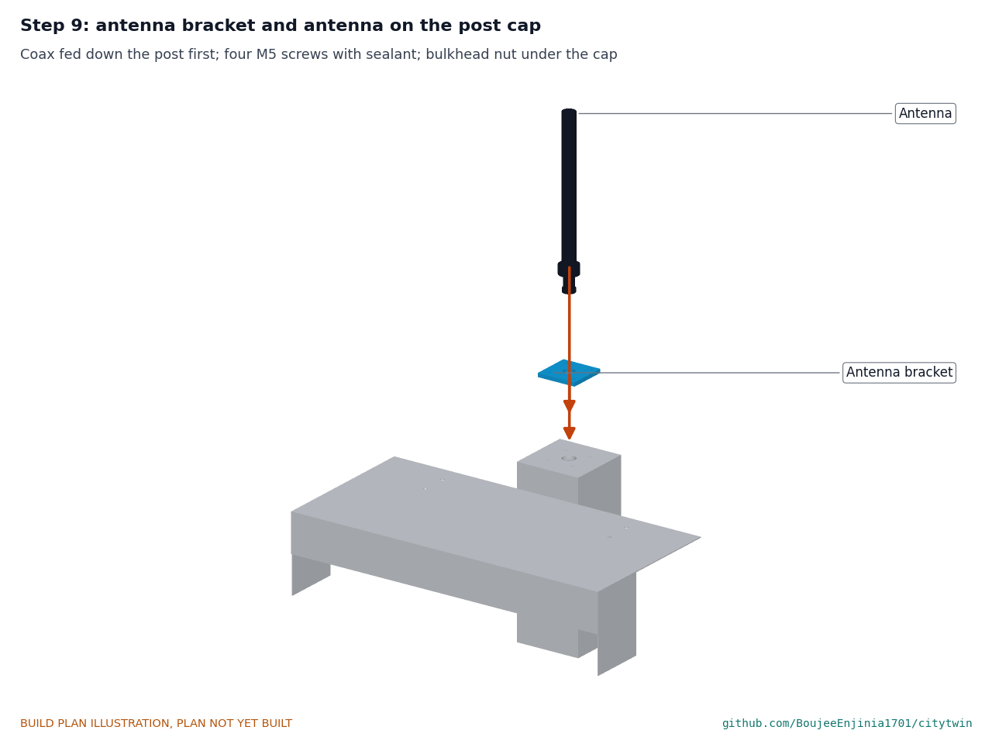
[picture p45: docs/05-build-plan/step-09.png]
Step 9


Pass the antenna cable up through the cap, connect it to the antenna's bulkhead, push the bulkhead through the bracket and the cap and fit its nut underneath. Fit the bracket with four M5 screws and a bead of sealant. **Hold point:** safety stop S5 before you climb.

### Step 10: buttons and notice plate onto the front panel

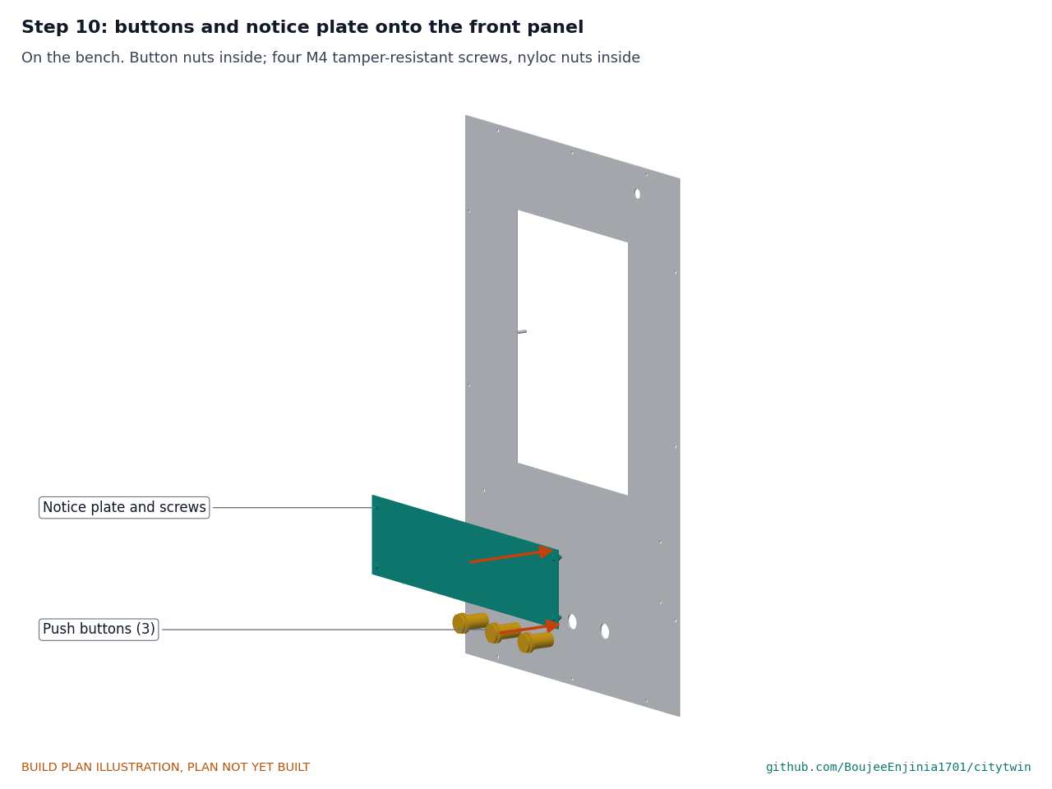
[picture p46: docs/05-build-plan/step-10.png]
Step 10


On the bench, with the panel face up. Fit each button through its hole and tighten its nut from behind. Fit the notice plate with four M4 tamper-resistant screws and nyloc nuts.

### Step 11: window onto the front panel

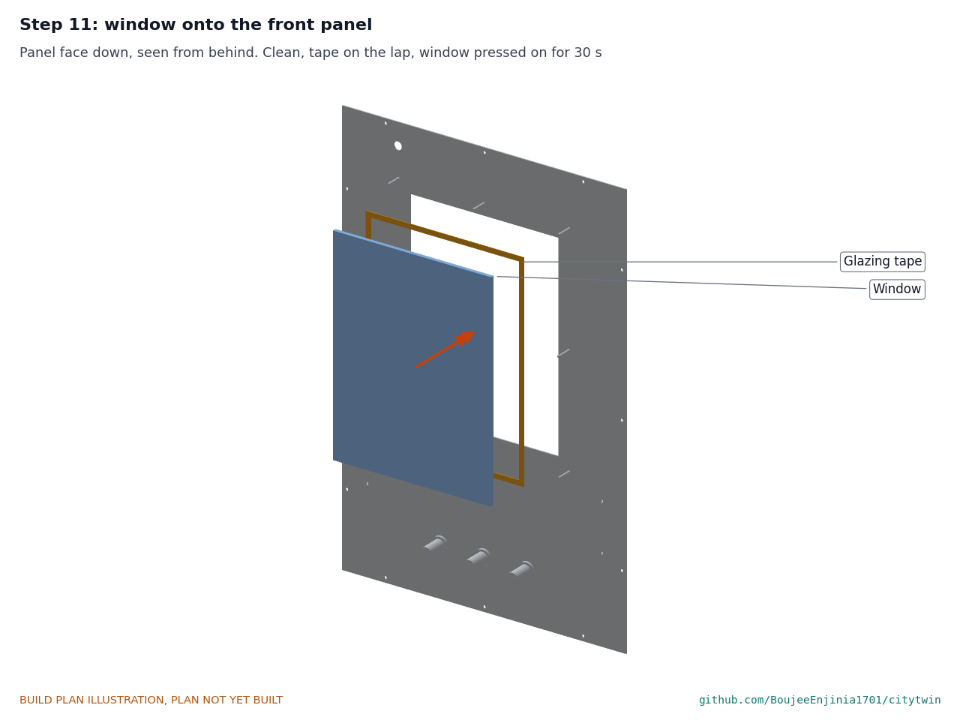
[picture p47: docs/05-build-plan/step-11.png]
Step 11


Turn the panel face down on a soft cloth. Clean the 8 mm band round the opening and the window's edge with isopropyl alcohol, lay the glazing tape on the band, peel its liner and press the window on for 30 seconds all round.

### Step 12: foam gasket and e-paper panel

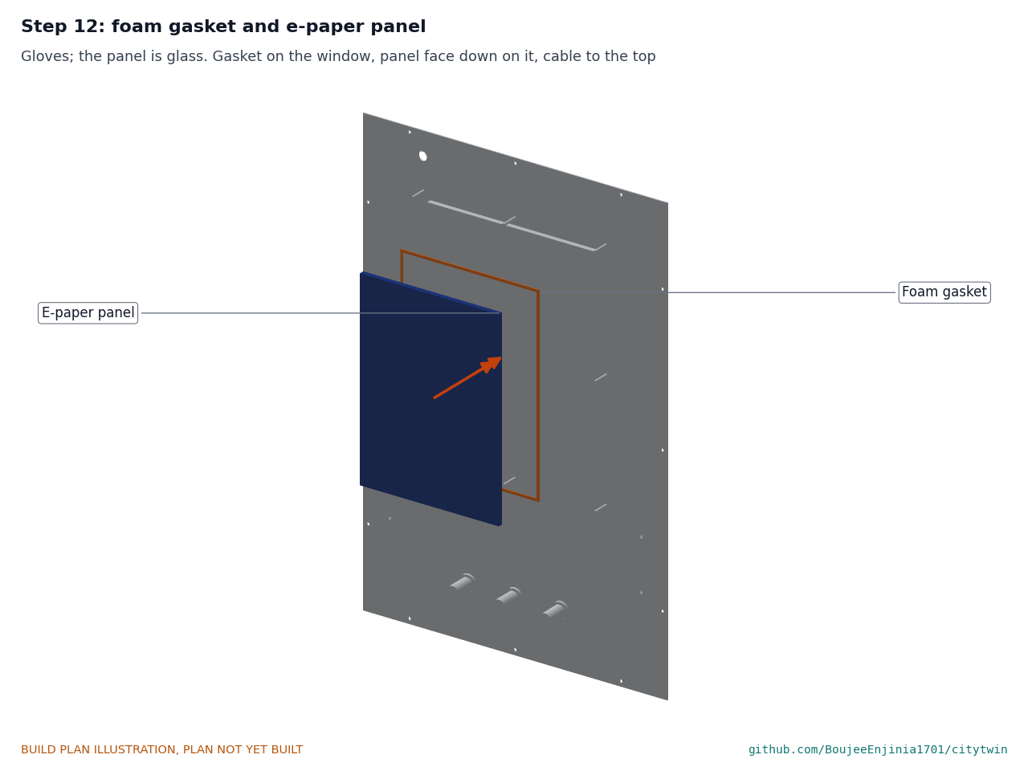
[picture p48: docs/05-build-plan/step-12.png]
Step 12


Wearing clean gloves, lay the foam gasket round the window's back over the panel's border area, then lay the e-paper panel face down on it, centered, with its flat cable toward the top.

### Step 13: display carrier onto the studs

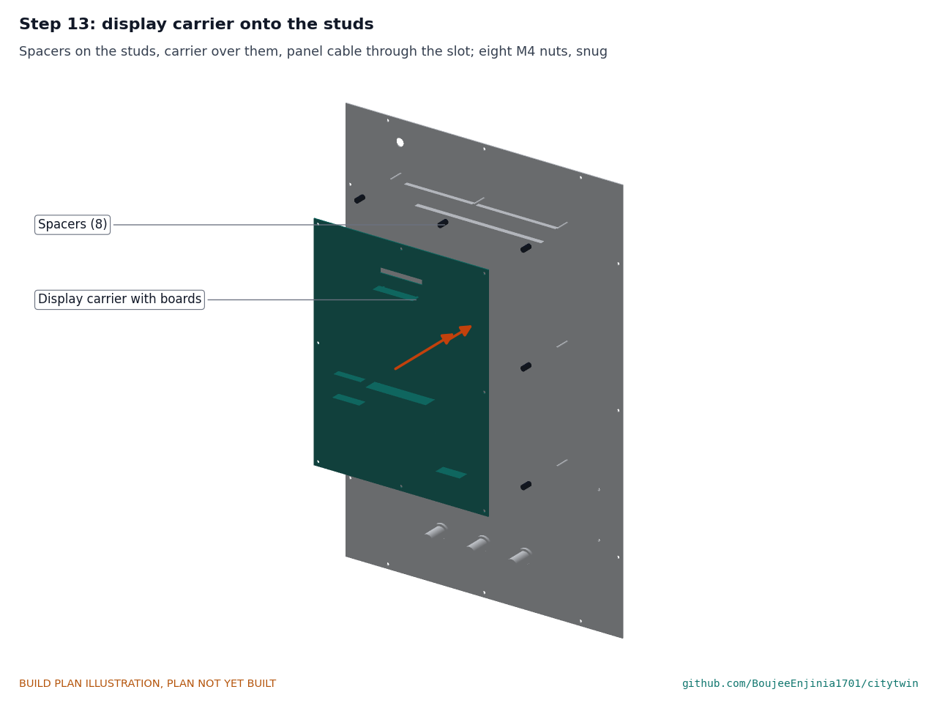
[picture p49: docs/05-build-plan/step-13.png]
Step 13


Slide a spacer onto each stud, pass the panel's flat cable through the carrier's slot and lower the carrier, with its boards already fitted and wired, over the studs. Fit eight M4 nuts snug, working across, so the panel is held but not stressed. Connect the flat cable to the driver board.

### Step 14: front panel onto the head tray

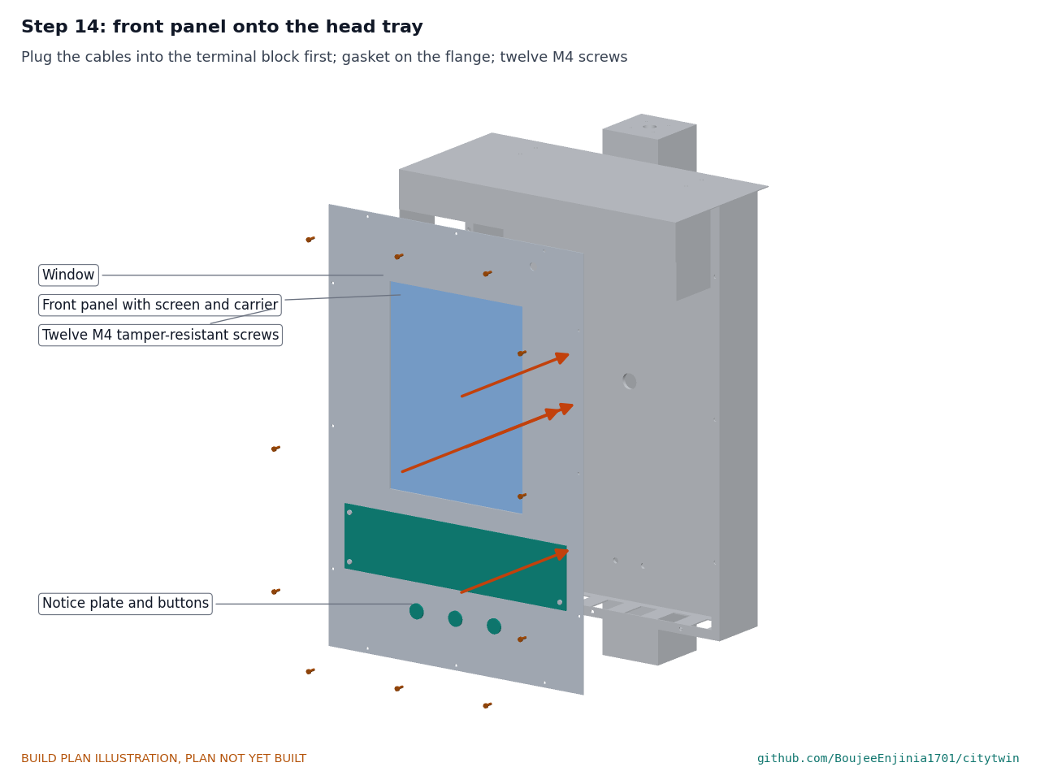
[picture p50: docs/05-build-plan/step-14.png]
Step 14


Plug the 12 V cable, the Ethernet cable and the LED cable into the terminal block and controller, lay the gasket strip on the tray flange, and fit the panel with twelve M4 tamper-resistant screws, tightened evenly. **Hold point:** safety stop S6.

### Step 15: sun shield onto its standoffs (outdoor sites only)

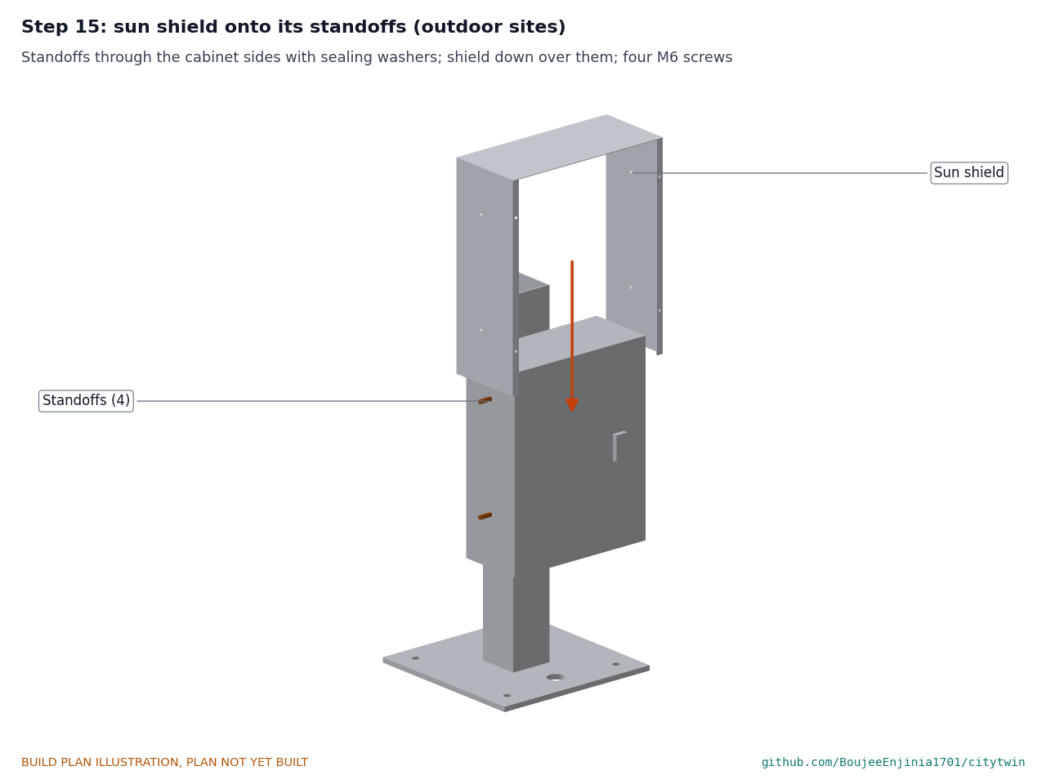
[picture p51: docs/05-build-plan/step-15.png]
Step 15


Bolt the four standoffs through the cabinet sides from inside, with a sealing washer under each bolt head. Lower the shield over them and fit four M6 tamper-resistant screws through its sides.

### Step 16: shield back panel (outdoor sites only)

Step 16

Hold the back panel on the shield's back flanges and fit the four thumb screws finger tight. **Hold point:** safety stop S7.

## 5. First checks

These are the checks a TRL 4 test report would record; this plan only lists them. Requirement numbers are those of CTW-REQ-001.

*Table 2. First checks.*

| Check | Requirement | How | Pass when |
| --- | --- | --- | --- |
| Electrical installation | R14 | Electrician's inspection and tests to local code: earth continuity, insulation, RCBO trip time with its test button and a tester | All pass; only 12 V reaches the post and head |
| 12 V supply | R14 | Meter at the head's terminal block with the front panel open | 12 V, give or take 0.5 V; the 2 A fuse in place |
| Button response | R10 | Press each button and time the LED ring and the new layer | Ring lights within 0.5 s and stays lit; new layer within 25 s |
| Reach and overhang | R11 | Tape measure from the sidewalk and from the post faces | Buttons 1,120 mm up; nothing overhangs the post more than 305 mm between 685 and 2,030 mm |
| Night light | R9 | Cover the dusk sensor; read the screen at 1.5 m in a dark room | Light on, dimmed; 7 mm capitals readable |
| Running power | R15 | Energy meter on the mains feed over 24 h | 15 W average or less (9.2 W expected) |
| Outage | R18 | Switch the RCBO off for 30 min | The screen keeps its last image and time stamp; the gateway runs on its pack |
| Pilot climate | R12 | Temperature loggers in the head and the cabinet for a week on the pilot site | Panel under 40 °C and cabinet under 45 °C at the hottest hour |
| No exposed ports | R19 | Look over the closed kiosk | No socket, USB port or screw that opens the head without a special bit |
| Head seal | R12 | Gentle hose spray on the closed head for 5 min (the IP test comes later) | No water inside the head |
| Post plumb and anchors | R13 | Level on two faces; torque wrench on the anchor nuts | Plumb within 2 mm per meter; nuts at the maker's torque |
| Mass | Handling (CTW-CAL-001 [H4]) | Weigh the post assembly before lifting, or sum the parts | About 64 kg with the shield; a two-person or hoist lift |

## 6. Safety stops

Stop at each point. Carry on only when everything listed is true.

- **S1. Before the post is lifted.** The footing is cured and designed for the site (or the bench block is level and anchored); two people or a hoist are ready; the work area is closed to the public; gloves and safety boots are worn.
- **S2. Before any mains wiring.** The feed is isolated and locked off at its source by the electrician, who does or checks all mains work; the cabinet's earth stud is bonded to the post.
- **S3. Before mains is first switched on.** The electrician's tests in section 5 pass; the RCBO trips on its test button; no mains wire leaves the cabinet; the cabinet door closes and locks.
- **S4. Before the gateway's backup pack fuse goes in.** The pack's voltage is within its maker's range, it has its own protection board and fuse, it shows no swelling, and the cabinet is out of direct sun or under its shield. Never defeat the gateway's 0 to 45 °C charge lockout.
- **S5. Before working on the post top.** A stable ladder or platform and a second person; no work in wind or rain; nothing dropped on the walkway below.
- **S6. Before 12 V is switched on to the head.** The terminal block's polarity is checked with a meter; the 2 A fuse is in; the e-paper panel's flat cable is seated; no wire is pinched by the front panel.
- **S7. Before the kiosk is left unattended.** Every tamper-resistant screw is in; the cabinet is locked; no sharp edge or corner at head height; the hood corners are rounded; the area round the post is clear for a walkway as local rules require.

## 7. Tools, skills and workspace

**Tools.** Bench drill or a drill in a stand; drills 2.5 to 13 mm; step drill to 33 mm; hole saw or punch for 25 mm holes in 4 mm steel; 90 degree countersink; rivet nut setting tool for M4, M5 and M8, steel and aluminum; M5 tap; tamper-resistant driver bits to match the screws; torque wrench; spirit level; tape measure and steel rule; scriber; deburring tool and files; caulking gun and sealant; isopropyl alcohol and lint-free cloths; clean nitrile gloves; ferrule crimper and wire strippers; soldering iron; multimeter; a hoist or two people; a stable ladder. The steel fabricator welds, galvanizes and coats the post; the sheet metal shop folds and coats the sheet parts.

**Skills.** Metalwork with drills and rivet nut tools, careful handling of a thin glass display, low-voltage wiring and crimping. Welding of the post and base plate is done by a qualified welder at the fabricator. All mains wiring and testing is done by a qualified electrician; the rest of the build is extra-low voltage (12 V).

**Workspace.** A bench about 1.5 x 0.8 m for the front panel and display work, clean and free of metal chips; a separate metalwork corner; a floor area about 2 x 2 m with headroom of 3 m to stand the post on its test block; a dry, ventilated place for sealant and glazing tape to cure.

**Personal protective equipment.** Safety glasses for drilling and cutting; cut-resistant gloves for sheet metal; safety boots and gloves for lifting the post; clean gloves for the display; no gloves near a turning drill.

## 8. Where the numbers come from

- Model and constructability checks: `cad/src/model.py` (`python cad/src/model.py --check`); STEP and STL exports in `cad/step/` and `cad/stl/`.
- Pictures: `cad/src/build_plan_media.py`, using `.kit/build_views.py`; written to `docs/05-build-plan/` and `cad/drawings/CTW-DWG-101` to `CTW-DWG-111`.
- General arrangement: `cad/drawings/CTW-DWG-001.pdf`, Rev P5.
- Calculations: `docs/04-calcs/01-sizing.md` (CTW-CAL-001 v0.5) and `docs/04-calcs/sizing.py`; wind and anchors [H1] to [H6], mass [H4], power [G1], timing [C2], cost [J1].
- Bill of materials: `bom/bom.csv`.
- Decisions: `docs/decisions/0003-design-for-construction.md` (CTW-DDR-003), with CTW-DDR-001 and CTW-DDR-002.
- Requirements: `docs/03-requirements.md` (CTW-REQ-001 v0.8).

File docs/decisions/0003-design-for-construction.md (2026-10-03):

---
doc_id: CTW-DDR-003
title: CityTwin design for construction
project: CityTwin
doc_type: Design decision record
version: "0.5"
status: Draft
date: '2026-10-02'
author: Amish Chadha
license: CERN-OHL-S-2.0
revisions:
- version: "0.1"
  date: '2026-10-01'
  author: Amish Chadha
  change: Changes that make the kiosk physically buildable, with the reason for each; made under Amish's 2026-09-30 instruction to make the design physically buildable; open for his review
- version: "0.2"
  date: '2026-10-01'
  author: Amish Chadha
  change: Budget treated as a value-engineering target, with cost question A1 replaced by the register's Value engineering section
- version: "0.3"
  date: '2026-10-02'
  author: Amish Chadha
  change: A2 accepted by Amish on 2026-10-02 as recommended (standoff holes drilled only in cabinets that get the shield); the Table 1 changes stay open for his review
- version: "0.4"
  date: '2026-10-02'
  author: Amish Chadha
  change: "Table 1 changes (P1 to P14) accepted by Amish on 2026-10-02"
- version: "0.5"
  date: '2026-10-02'
  author: Amish Chadha
  change: "Consequences: render scene exported from the current model; A2 holes now only on the shielded cabinet in the model"
---

# 0003: Design for construction

- **Date:** 2026-10-01
- **Status:** accepted. Amish, 2026-10-02: "APPROVED: Design-for-construction changes in 10 repos (CityTwin, CoolShade, PalletPilot, Heliolite, PotholeLog, EarthPress, ReadyKit, CellCheck, CargoMule and ThermaCart)". This covers the changes P1 to P14 in Table 1, made under Amish's 2026-09-30 instruction to make the design physically buildable, and is recorded in the design decisions register (CTW-DEC-001). The item in Table 3 (A2) was accepted earlier the same day as recommended (Amish, 2026-10-02: "i approve your recommendations for all 555 open decisions.") and is recorded in the register too.

## Context

On 2026-09-30 Amish asked for every repo to get an illustrated build plan that shows how each component is made and how it fits the next, and wrote: "If you are realising that the design cannot be built as per concept - fix the design assumptions to match and be physically feasible as you draw the illustrations." The concept model of CTW-DDR-002 showed what the CityTwin kiosk does, where its parts sit and how big they are, but it was a massing model: the head, cabinet and hood touched the post with nothing holding them, the head was a sealed box with no way in, the screen and controller floated in the head, and several cable and conduit routes ran into solid walls.

Checking the model with build123d (intersections, volumes and distances between every pair of parts) found 14 problems, P1 to P14 below. The fixes keep what the kiosk does: the same post, base plate, head, window, screen position, buttons, notice plate, hood, cabinet, rails, gateway layout, antenna height and sun shield, the same mains and 12 V split, and the same sheltered pilot and outdoor site rules. Nothing here changes the pitch or the safety case. Every change is in `cad/src/model.py`, which now runs 244 constructability checks (`python cad/src/model.py --check`): no two parts overlap, the 50 pairs that must touch do touch, and the 10 pairs that must stay apart keep their gap. All 244 pass.

## Decision

*Table 1. Changes made to the model, the BOM and the calculations.*

| # | Problem in the concept | Change made | Why this way |
| --- | --- | --- | --- |
| P1 | The head and the cabinet touched the post with no fixing. The post is a closed 100 mm tube, so nothing can be reached inside it to hold a nut. | Eight M8 steel flush rivet nuts set in countersunk 11 mm holes in the post: four in the front wall (head, at 1,100 and 1,660 mm) and four in the back wall (cabinet, at 360 and 700 mm), 25 mm each side of the center line. The head and the cabinet are each held by four M8 button-head screws with 30 mm washers, put in from inside. | Rivet nuts are set from outside a closed tube; flush heads keep the head and cabinet flat on the post. Holes are drilled before galvanizing and the nuts set after coating, so the threads stay clean. The 30 mm washers spread the load on the 2 mm aluminum tray. |
| P2 | The display head was a closed 2 mm aluminum box: there was no way to fit or service anything inside it, and no way to make it as one folded part. | The head is now a folded tray (back, top, bottom, sides, 98 mm deep) with a 15 mm return flange round its front, closed by a separate 2 mm front panel on twelve M4 tamper-resistant screws into rivet nuts in the flange, with a gasket strip. Outside size unchanged at 460 x 100 x 680 mm. | A sheet metal shop can fold the tray; the front panel comes off for service and the screws resist tampering, as BOM item 3 already asked. |
| P3 | The window sat inside the front wall with no fixing. | The window is bonded inside the front panel with 1 mm acrylic glazing tape on its 8 mm lap. | The common way to glaze a kiosk; it also seals the window edge. |
| P4 | The e-paper panel floated 1 mm behind the window, and the controller floated on a block near the back wall. | New BOM item 20, a 2 mm aluminum display carrier, sits on 15 mm spacers over eight M4 clinch studs pressed into the front panel. It presses the e-paper panel onto a 1 mm foam gasket on the window and carries the driver board and the controller on M2.5 standoffs. | One plate holds the fragile glass panel evenly and keeps the electronics with the screen, so the whole display lifts out with the front panel. |
| P5 | The head had only a 12 V feed, but the controller needs 5 V, the button rings and the dimmed hood light need switching, and nothing let the front panel unplug. | BOM item 6 now includes a 12 V to 5 V converter, a 4-channel LED driver module and a pluggable 6-way terminal block with a 2 A fuse, all on the carrier. Item 6 rises from $42.00 to $55.00. | The controller rules of CTW-DDR-002 (LED ring on press, hood light dimmed to about 0.3 W) need these; the fuse protects the 12 V cable up the post. |
| P6 | Buttons were drawn as 24 mm cylinders in 24 mm holes. | 19.2 mm holes; each button's 24 mm bezel sits outside the panel and its own nut clamps it inside. | That is how a 19 mm vandal-resistant button mounts. |
| P7 | The notice plate had no fixing. | Four 4.5 mm holes and four M4 tamper-resistant screws with nyloc nuts inside the front panel. | Reachable once the front panel is off; tamper-resistant from the street. |
| P8 | The hood roof was a 14 mm solid block with no fixing, and the LED strip floated below it. | The hood is folded 1.5 mm sheet (roof, lip, cheeks) resting on the tray top, held by four M5 tamper-resistant screws into rivet nuts in the tray top. The LED strip sits on a 20 x 20 mm angle riveted under the roof behind the lip; its cable enters the head through a 13 mm grommet in the front panel, under the roof. | A real folded part with a real fixing. The head's leading edge drops from 1,734 to 1,722 mm, still inside the 685 to 2,030 mm zone. |
| P9 | DIN rails were drawn on the cabinet wall itself. | The rails sit on the cabinet's 340 x 390 mm mounting plate on 10 mm standoffs, as a stock cabinet supplies it. | Lets the cabinet screws go in first, then the plate; every device keeps at least 10 mm from the door. |
| P10 | The 16 x 60 mm cable slot in the post back met a solid cabinet wall, and there was no cable route from the post into the head. | A 25 mm hole through the post back wall and the cabinet wall at 735 mm (above the mounting plate), and a 25 mm hole through the post front wall and the tray back at 1,380 mm, each with rubber grommets. The 12 V cable, Ethernet and coax run up inside the post. | Round holes are simpler to make and seal than a slot; both routes stay inside the post, out of reach. |
| P11 | The mains conduit stopped on top of the base plate and on the cabinet floor with no holes. | A 40 mm hole in the base plate, 130 mm behind the post center, and a 32 mm conduit gland in the cabinet floor. | The feed comes up from the footing without passing through the post, keeping mains out of the post. |
| P12 | The anchors were fused to the base plate, and the post was a closed steel tube, which cannot safely be hot-dip galvanized. | 18 mm anchor holes, 34 mm washers and nuts; a 25 mm vent and drain hole in the base plate under the post; the cap's 20 mm coax hole vents the top. | Galvanizers need vent holes at both ends of a closed section; the bottom hole also drains condensation. |
| P13 | The antenna bracket was a solid 60 x 60 x 20 mm block. | A 60 x 60 x 6 mm aluminum plate with a 16.5 mm hole for the antenna's N-type bulkhead, held to the post cap by four M5 screws into tapped holes. The antenna base makes up the rest of the height, so the tip stays at 2.38 m. | A plate a small shop can make; the coax passes straight down into the post. |
| P14 | The sun shield's two hook tabs hooked onto nothing, and its "lift-off" back panel was one piece with the rest. | The shield (top and sides) sits on four 25 mm M6 standoffs bolted through the cabinet sides with sealing washers. A 15 mm flange folded inward at the back of each side carries a separate back panel, held by four M5 knurled thumb screws into rivet nuts. | The 25 mm air gap, open bottom and top vents are unchanged, so the thermal result stands. The back panel comes off by hand to reach the locked door. |

*Table 2. Knock-on changes.*

| Item | Change | Reason |
| --- | --- | --- |
| BOM | Lines 1 to 4, 6 to 10, 14, 15 and 19 respecified; line 6 repriced to $55.00; line 15 repriced to $26.00 (fixings moved out); new line 20 (display carrier, $8.00) and line 21 (fixings, tapes and gaskets, $22.00). 21 lines. | Parts added for construction. |
| Cost | Pilot kiosk $739.00 to $778.00 [J1], $28.00 over the $750 value-engineering target [J2]; outdoor kiosk $808.00; with the TwinKit gateway $1,068.00. R16 changes from met on paper to **over the value-engineering target by $28.00**. | See the Value engineering section of CTW-DEC-001. |
| Mass | 60.1 to 63.5 kg with the sun shield [H4]. Most of the rise is the cabinet's 2 mm steel mounting plate (2.1 kg), then the front panel and fixings. | Still a two-person or hoist lift. |
| Wind | The hood is now modeled as sheet, not a 14 mm block: 827 to 821 N, post stress 26.9 to 26.6 MPa, anchor tension 1.97 to 1.94 kN [H1, H2, H5]. R13 still met on paper. | Follows the model. |
| Thermal, power, radio, legibility | Unchanged. The window, screen gap, hood, cabinet and shield keep their sizes and positions. | |
| Drawing | CTW-DWG-001 Rev P4; making sketches CTW-DWG-101 to 111 added. | Follows the model. |
| Documents | CTW-CAL-001 v0.3, CTW-REQ-001 v0.5, CTW-PRC-001 v0.5 updated for cost, mass and wind. New CTW-BLD-001 and CTW-DEC-001. | Follows the model. |

*Table 3. Proposed, then accepted by Amish as recommended on 2026-10-02.*

| # | Question | Options | Recommendation |
| --- | --- | --- | --- |
| A2 | The sun shield standoff holes breach the cabinet's sides. | (a) drill them only on kiosks that get the shield; (b) drill every cabinet so a pilot kiosk can later move outdoors, with sealed blanking screws until then. | (a), so the sheltered pilot cabinet keeps its unbroken IP55 sides. Accepted 2026-10-02. |

## Consequences

- `design_state: constructable` in `project.yaml`. The build plan CTW-BLD-001 shows every component and step in pictures generated from the model (`cad/src/build_plan_media.py`); open items are in the design decisions register CTW-DEC-001.
- Requirement status (CTW-CAL-001 v0.3): 2 not met (R18, R20), 1 over the value-engineering target (R16), 1 at risk (R1), 9 met on paper, 7 met by design. Before: 2 not met, 1 at risk, 10 met on paper, 7 met by design.
- The photoreal renders (`media/render-*.png`), `media/card.png` and `media/social-preview.png` are made on Amish's Mac from the scene exported from the current model (`cad/src/concept_media.py`, `.kit/scene_export.py`); they are remade there, so they may differ from the model until then. The concept media in `media/` were regenerated from the new model.
- The cabinet, its mounting plate, the e-paper panel's outline and cable exit, and the rivet nuts' grip range are bought parts to be confirmed when chosen at TRL 4 (CTW-DEC-001).

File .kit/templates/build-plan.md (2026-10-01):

---
doc_id: PRJ-BLD-001
title: Project prototype build plan
project: Project name
doc_type: Build plan
version: "0.1"
status: Draft
date: YYYY-MM-DD
author: Amish Chadha
license: CERN-OHL-S-2.0
revisions:
  - version: "0.1"
    date: YYYY-MM-DD
    author: Amish Chadha
    change: First build plan; design made constructable
---

# Project prototype build plan

**Plan, not yet built.** How to build the first proof-of-concept prototype, component by component. Building and testing to it is TRL 4 work. Decisions still to be made are kept in the design decisions register (`docs/06-design-decisions.md`), not here.

## 1. What you are building

Every component, pulled apart and numbered in build order

One short paragraph: what the prototype is, how many components, which are made and which are bought, and the main ways they are made.

## 2. What changed to make it buildable

| Component | The concept had | The buildable design has | Why |
| --- | --- | --- | --- |

## 3. Making the components

### 3.1 Component name

Making sketch

**What it is and what it is made from.**

**How to make it.**

1. Mark out ...
2. Cut ...

**How it fits the parts next to it.**

Close-up of the joint

**Check before moving on.**

## 4. Putting it together

### Step 1: ...

Step 1

## 5. First checks

| Check | Requirement | How | Pass when |
| --- | --- | --- | --- |

## 6. Safety stops

## 7. Tools, skills and workspace

## 8. Where the numbers come from

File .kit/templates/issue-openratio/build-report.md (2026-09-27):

---
name: Build report
about: Tell us what happened when you built, printed or tested part of this design
title: "Build report: "
labels: build-report
---

This is a research and educational prototype, not a medical device. It is a TRL 3 concept and is not released for fabrication. If you build any part of it, you do so at your own risk. Reports help everyone.

**What you built** (part, sub-assembly or test)

**Materials, tools and settings**

**What worked**

**What did not work, with photos or measurements if you have them**

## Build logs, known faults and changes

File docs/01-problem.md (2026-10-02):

---
doc_id: CTW-PRB-001
title: CityTwin problem statement
project: CityTwin
doc_type: Problem statement
version: "0.6"
status: Draft
date: '2026-10-02'
author: Amish Chadha
license: CERN-OHL-S-2.0
revisions:
- version: "0.1"
  date: '2026-09-25'
  author: Amish Chadha
  change: Initial scaffold
- version: "0.2"
  date: '2026-09-25'
  author: Amish Chadha
  change: Populate to TRL 2 (problem, users, context, constraints, prior work, open questions)
- version: "0.3"
  date: '2026-09-25'
  author: Amish Chadha
  change: TRL 3 update per CTW-DDR-001 and CTW-CAL-001 (reference neighborhood rates, pilot siting, budget scope, adopted license and privacy settings, sibling upload paths)
- version: "0.4"
  date: '2026-09-25'
  author: Amish Chadha
  change: Recommendations accepted by Amish (DDR-002)
- version: "0.5"
  date: '2026-10-01'
  author: Amish Chadha
  change: Kiosk parts cost updated for the constructable design (CTW-DDR-003)
- version: "0.6"
  date: '2026-10-02'
  author: Amish Chadha
  change: First candidate partner city and sheltered pilot site, as decided by Amish on 2026-10-02
---

# CityTwin problem statement

City data sits in separate vendor dashboards, and residents rarely see the data collected on their streets. Where street sensing has been proposed without clear rules on who holds the data and what leaves the device, it has lost public trust.

## The problem

A city that installs counters, air and noise sensors, flood gauges and curb sensors usually buys each from a different vendor, with a different dashboard, data format and contract. The data stays in those silos, so a planner cannot put pedestrian counts next to air quality or flooding on one map, and a resident walking past a sensor cannot see what it measures, who is responsible for it, or the data it has collected.

Trust is the second problem. In a 2019 survey, 66 % of U.S. adults said the potential risks of government data collection about them outweigh the benefits, and 84 % said they have very little or no control over the data government collects about them ([Pew Research Center, 2019](https://www.pewresearch.org/internet/2019/11/15/americans-and-privacy-concerned-confused-and-feeling-lack-of-control-over-their-personal-information/)). In Toronto, Ontario's former privacy commissioner Ann Cavoukian resigned from the Sidewalk Labs project because de-identification at the source of collection could not be guaranteed for all participants ([CBC News](https://www.cbc.ca/news/canada/toronto/ann-cavoukian-sidewalk-data-privacy-1.4872223)); the project was later withdrawn on May 7, 2020, with Sidewalk Labs citing economic uncertainty ([Sidewalk Labs](https://medium.com/sidewalk-talk/why-were-no-longer-pursuing-the-quayside-project-and-what-s-next-for-sidewalk-labs-9a61de3fee3a)).

The lab's smart city set (CurbCount, CrossSafe, PotholeLog, DockHub, LoadZone, HeatMap Node, FloodGauge, AirStreet and NoiseMap) already follows one privacy rule: counts or levels only, with no images or audio leaving the device. What is missing is the layer that brings their data together, applies the same rules to what is published, shows it to residents in the street, and exports it as open data.

## Prior work

- **Open sensor platforms.** Barcelona's [Sentilo](https://www.sentilo.io/) is an open-source sensor and actuator platform built so a city can avoid technological silos. [Civil IoT Taiwan](https://ci.taiwan.gov.tw/) publishes air quality, water, earthquake and disaster sensor data as open data. Both are city- or nation-scale platforms, not a kit a small city or neighborhood group can run.
- **Open standards for sensor data.** The [OGC SensorThings API](https://www.ogc.org/standards/sensorthings/) is an open, geospatial standard for IoT observations and metadata.
- **Transparency in public space.** [Digital Trust for Places and Routines (DTPR)](https://dtpr.io/), stewarded by Helpful Places, is an open communication standard with icons for signage that explain what a sensor in public space does.
- **Community sensing.** [AirQo](https://airqo.net/), a Makerere University project, runs more than 400 low-cost air quality sensors in 14 African countries and publishes the data to the public.
- **Lab dependencies.** CityTwin runs on the TwinKit gateway (LoRaWAN concentrator, MQTT broker, time-series database) and reads the nine smart city nodes listed above.

None of these combines a small open gateway, one privacy rule set across many node types, a public street kiosk and an open data export in one design that a small team can build and audit.

## Users and context

Table 1. Users and needs.

| User | Need | Context |
| --- | --- | --- |
| Resident or passer-by | See what is measured on their street, by whom, and the current values, without an app | At the kiosk on a sidewalk, square or transit stop; on a phone through the QR code |
| City planner or engineer | One map of counts, curb use, air, noise, heat and flooding to compare before and after a street change | Office, on the city network |
| Data protection officer | Evidence that published data holds no personal data and follows retention rules | Privacy impact assessment and audit |
| Community group or school | Open files to analyze, and a kiosk to host at a library or community center | Local projects and teaching |
| Researcher or journalist | Documented, reusable open data under an open license | Download or API |
| Maintenance crew | Node health and alerts (battery, last seen, flood alerts) | Depot or field |

**Operating environment (kiosk).** Outdoors on a sidewalk or plaza, in rain, sun and dust, from about -20 °C to +45 °C air temperature depending on the city, with exposure to vandalism. Mains power from a street lighting circuit or an adjacent building. Indoor variants (library, city hall lobby) are simpler. Under CTW-DDR-001 D3 (decided by Amish, 2026-09-25) the pilot kiosk stands on a sheltered site with no direct sun on the screen, and under CTW-DDR-002 its air range is 0 to 35 °C, because the color e-paper is rated only 0 to 40 °C and needs margin; the full street range is the target after the pilot (CTW-REQ-001 R20). Any outdoor site gets the cabinet sun shield and a shaded screen orientation as site rules, and a panel heater only if the partner city has frost.

**Reference neighborhood (for sizing, CTW-DDR-001 D9).** 46 LoRaWAN nodes: 8 CurbCount, 4 CrossSafe, 12 LoadZone pucks, 6 HeatMap Node, 4 FloodGauge, 6 AirStreet and 6 NoiseMap, plus PotholeLog on 3 buses and one DockHub. With the sibling repos' TRL 3 reporting rates they send 5,616 uplinks a day, within the 50 nodes and 10,000 records a day that one TwinKit gateway must carry (CTW-CAL-001). PotholeLog uploads its daily summaries to the fleet operator's server over depot Wi-Fi, and DockHub syncs over LTE-M to its own back end; CityTwin pulls their published aggregates by outbound connections (D11, decided by Amish on 2026-09-25; formats still to be agreed with those repos).

## Constraints

- Garage-buildable prototype. `budget_usd` is $750 (raised from $600 under CTW-DDR-002) and, under D1, covers the pilot kiosk only; the TwinKit gateway is costed in TwinKit. The pilot kiosk parts cost $778.00 after the parts added to make it buildable (CTW-DDR-003), $28.00 over `budget_usd`; the outdoor sun shield adds $30.00.
- Privacy by design: only counts and levels are taken in, stored or published; no images, audio or personal identifiers.
- Open software (MIT), open hardware (CERN-OHL-S-2.0) and open data under CC BY 4.0 (D7).
- Runs offline on one TwinKit gateway; no dependency on a vendor cloud.
- Mains work by a qualified electrician; street furniture installed only with the asset owner's permission.

## Out of scope

- Any camera, microphone, face or plate recognition, or tracking of individuals.
- Control of city systems (traffic signals, street lights). CityTwin shows and exports data; it does not actuate.
- Emergency alerting. FloodGauge alerts appear on the map, but CityTwin is not a public warning system.
- Large touch-screen advertising kiosks.

## Open questions

- Which city or neighborhood partner hosts the first kiosk? Decided by Amish on 2026-10-02: the first candidate to approach is a city within easy reach of Irving, Texas, with an active open-data program, the pilot in a sheltered public lobby such as a library or transit center (CTW-DEC-001).
- Open data license: CC BY 4.0 (D7), decided by Amish on 2026-09-25.
- Small-count threshold of 5 per hour and two years of raw data retention (D6), decided by Amish on 2026-09-25.
- Will PotholeLog's operators and DockHub publish aggregates that CityTwin can pull, and will CrossSafe add a LoRaWAN uplink? To agree with those projects.

## User research and co-design

This design is for communities the author is not part of, so requirements come from the people who will use it.

- [ ] Identify a local partner organization (Helpful Engineering network, NGO or university)
- [ ] Run co-design sessions with intended users; record who, where and what was learned
- [ ] Validate load, distance, terrain and cost assumptions in the field
- [ ] Revise requirements (REQ) from findings before freezing the design

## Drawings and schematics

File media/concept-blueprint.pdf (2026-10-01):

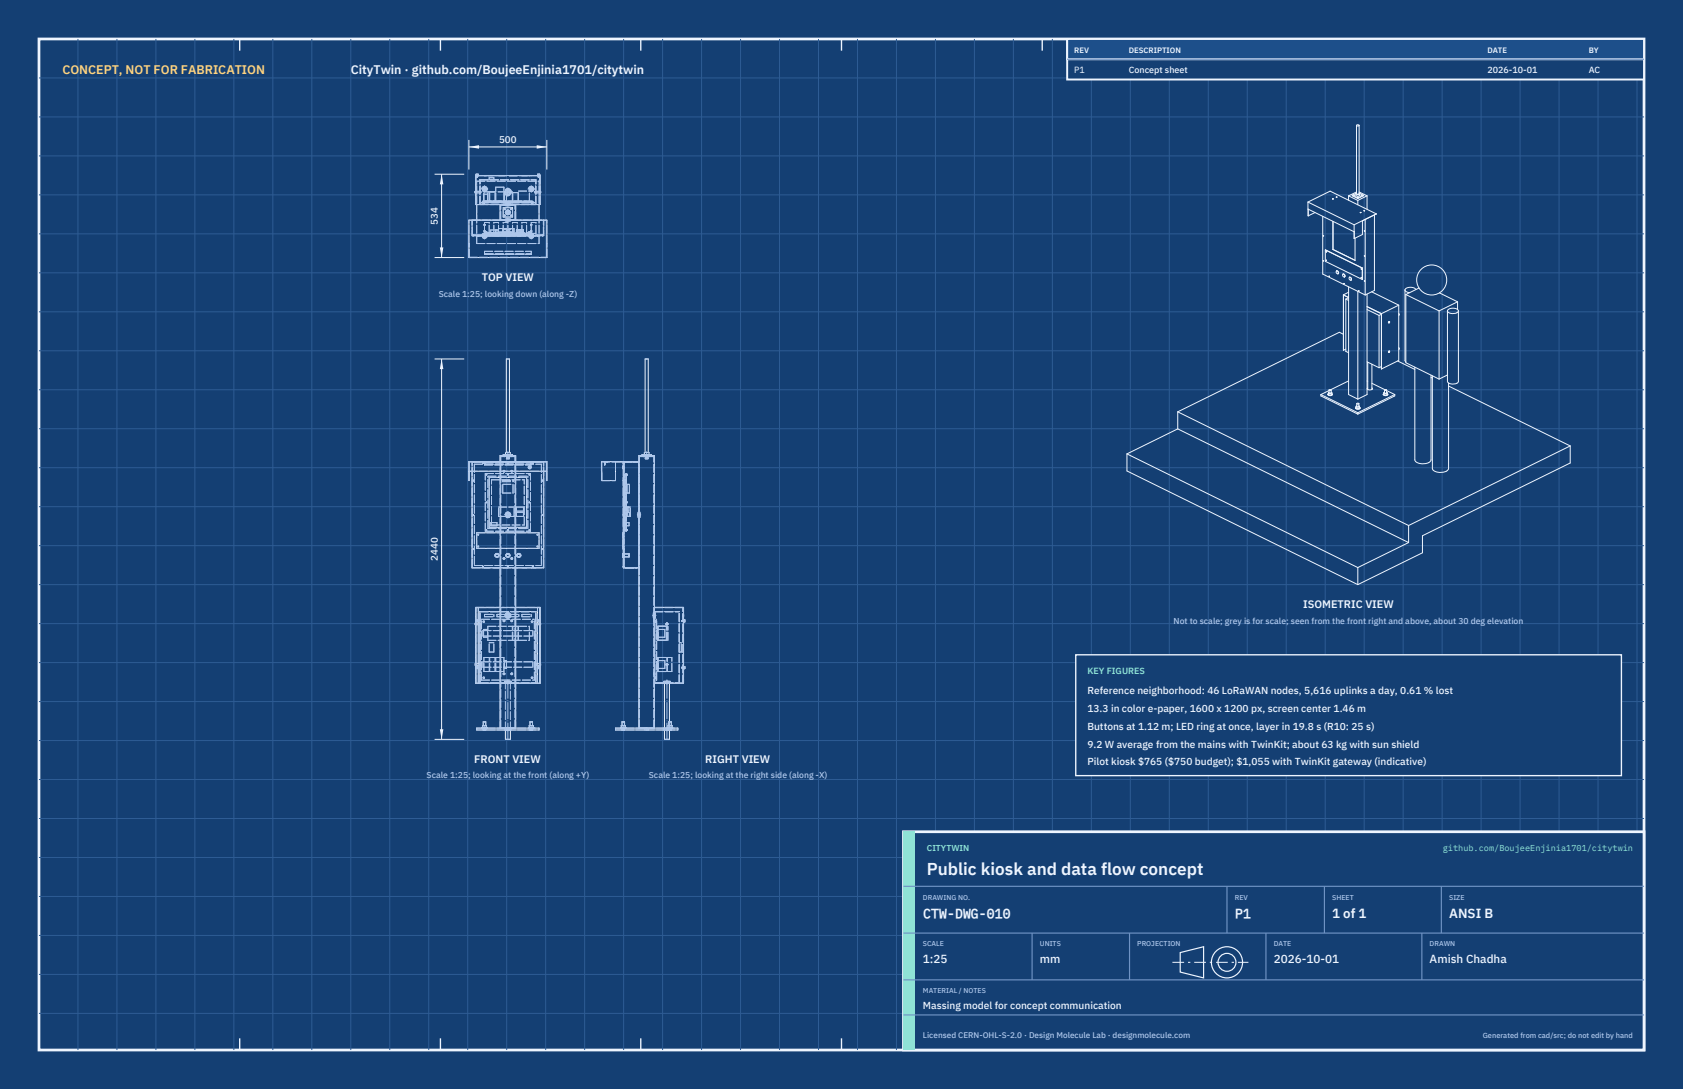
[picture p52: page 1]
CONCEPT, NOT FOR FABRICATION; CityTwin · github.com/BoujeeEnjinia1701/citytwin; FRONT VIEW; TOP VIEW; RIGHT VIEW; ISOMETRIC VIEW; REV; DESCRIPTION; DATE; Concept sheet; CITYTWIN; github.com/BoujeeEnjinia1701/citytwin; DRAWING NO. CTW-DWG-010; REV P1; SHEET 1 of 1; SIZE ANSI B; SCALE 1:25; UNITS mm; PROJECTION; DRAWN Amish Chadha; Licensed CERN-OHL-S-2.0 · Design Molecule Lab · designmolecule.com; Generated from cad/src; do not edit by hand

Scale 1:25; looking down (along -Z)

Not to scale; grey is for scale; seen from the front right and above, about 30 deg elevation

KEY FIGURES
Reference neighborhood: 46 LoRaWAN nodes, 5,616 uplinks a day, 0.61 % lost
13.3 in color e-paper, 1600 x 1200 px, screen center 1.46 m
Buttons at 1.12 m; LED ring at once, layer in 19.8 s (R10: 25 s)
9.2 W average from the mains with TwinKit; about 63 kg with sun shield
Pilot kiosk $765 ($750 budget); $1,055 with TwinKit gateway (indicative)

Scale 1:25; looking at the front (along +Y)

Scale 1:25; looking at the right side (along -X)

Public kiosk and data flow concept

MATERIAL / NOTES
Massing model for concept communication

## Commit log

2026-09-25 Initial scaffold: standard open hardware layout, CERN-OHL-S v2 + MIT licenses
    Claude-Session: https://claude.ai/code/session_01XuhhSU4W6fYhgCfURbrkut
    [bom.csv]
2026-09-26 Populate to TRL 2: problem, requirements, precis, concept media, BOM and README use cases
    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
    [bom.csv]
2026-09-26 Advance to TRL 3: DDR-001, CAL-001 sizing, parametric model with STEP/STL, GA drawing, priced BOM; TRL 4 on hold
    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
    [bom.csv, citytwin-kiosk-assembly.step, citytwin-kiosk-assembly.stl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]
2026-09-26 Accept all recommendations (DDR-002), switch footer to designmolecule.com, add README write-up with new inspiration point
    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
    [bom.csv, citytwin-kiosk-assembly.step, citytwin-kiosk-assembly.stl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]
2026-10-01 Image quality pass: legible exploded views, flow diagrams and drawing sheets
    Kit 1.6.1 image layout: the parts list sits in its own column, number bubbles sit on visible parts and never overlap, small parts get a leader, pictures are cropped to the subject, flow labels keep numbers with their units, and sheet captions and the revision table no longer overprint. Concept images, blueprint and general arrangement sheet regenerated; repo-specific labels moved clear of other text and lines.
2026-10-01 Kit 1.7.0: constructable design, illustrated build plan and design decisions register
    The design is now constructable: every part can be made and fits its neighbours, with each change recorded in a Design for construction decision record (made under Amish's 2026-09-30 instruction; ope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
    [bom.csv, citytwin-kiosk-assembly.step, citytwin-kiosk-assembly.stl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]
2026-10-01 Budget treated as a value-engineering target
    Amish, 2026-10-01: the budget is a hypothetical control target that keeps the design on a value-engineering lens, not a spending limit. Documents now state the value-engineering target and the estima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
2026-10-02 Record Amish's approval of the open-decision recommendations
    Amish approved the recommendation on every open decision in the design decisions register ("i approve your recommendations for all 555 open decisions.", 2026-10-02). Each decision is moved to Decisio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
2026-10-03 Carry approved follow-ups into the design and redo photoreal renders
    Amish approved the follow-up actions from the open-decision sign-off ("APPROVED CHANGES, COMPLETE THESE", 2026-10-02), the design-for-construction change tables in ten repos, the last wave's open dec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
    [bom.csv, citytwin-kiosk-assembly.step, kiosk-head.step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]

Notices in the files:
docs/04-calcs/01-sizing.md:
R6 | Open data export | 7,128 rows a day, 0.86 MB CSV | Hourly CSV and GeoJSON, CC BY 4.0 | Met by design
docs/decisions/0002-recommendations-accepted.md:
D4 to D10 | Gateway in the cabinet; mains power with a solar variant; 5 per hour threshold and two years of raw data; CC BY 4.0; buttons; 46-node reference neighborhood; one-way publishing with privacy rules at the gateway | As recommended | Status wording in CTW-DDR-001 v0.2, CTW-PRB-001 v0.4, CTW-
